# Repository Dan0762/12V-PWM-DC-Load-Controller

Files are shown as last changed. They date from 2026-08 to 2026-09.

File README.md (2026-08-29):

# 12V PWM DC Load Controller

A compact 2-layer PWM controller for 12 V DC loads, designed in Altium Designer.

The project is based on an NE555 timer and an N-channel MOSFET low-side power stage.
It was created as a practical PCB design project focused on schematic design,
component selection, power routing, grounding, DFM and manufacturing output generation.

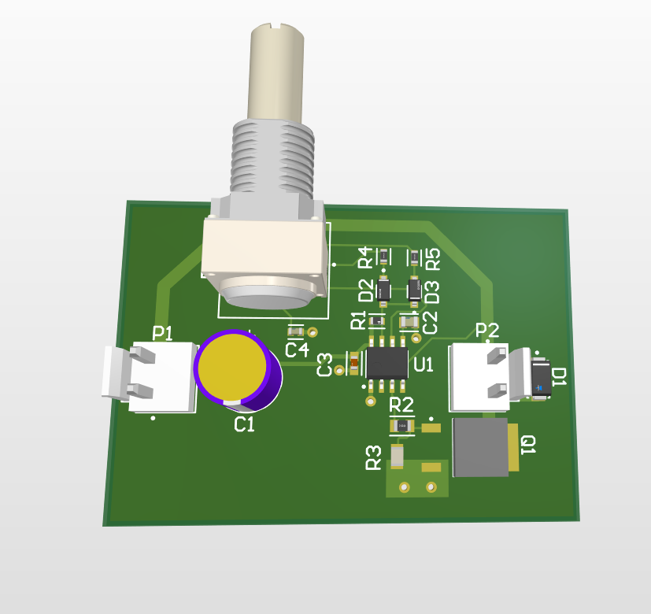
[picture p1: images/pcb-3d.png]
PCB 3D Render


## Overview

The controller generates an adjustable PWM signal at approximately 25 kHz and
switches an external 12 V load using a power MOSFET.

The output can be used with PWM-compatible resistive and inductive loads such as:

- DC motors
- solenoids
- lamps
- resistive heaters
- other 12 V DC loads

A Schottky flyback diode is included for inductive loads.

## Main Features

| Parameter | Value |
|---|---|
| Input voltage | 12 V DC nominal |
| PWM controller | NE555 |
| PWM frequency | ~25 kHz |
| Duty-cycle control | 50 kΩ linear potentiometer |
| Output topology | N-MOSFET low-side switch |
| MOSFET | Infineon IPD053N06N |
| Flyback diode | Vishay SSA34HE3 |
| Target load current | up to ~2 A |
| PCB layers | 2 |
| PCB material | FR-4 |
| PCB thickness | ~1.6 mm |
| Copper thickness | 1 oz |
| PCB software | Altium Designer |

> The ~2 A load capability is a design target. Physical load and thermal
> validation will be performed after PCB assembly.

## Schematic

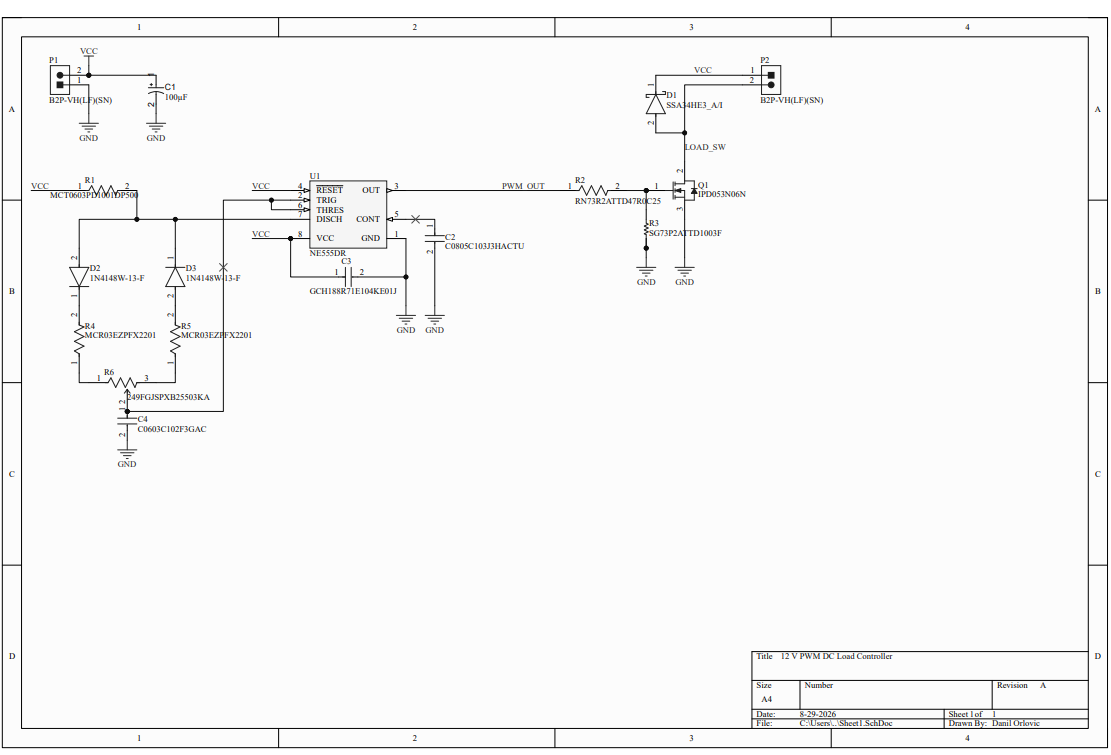
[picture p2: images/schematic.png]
Schematic


The circuit consists of three main functional blocks:

1. 12 V input and local decoupling
2. NE555 adjustable PWM generator
3. N-channel MOSFET power output stage

The NE555 uses separate capacitor charge and discharge paths through two
1N4148W diodes, allowing duty-cycle adjustment with a single potentiometer.

A 1 nF C0G timing capacitor was selected for good frequency stability.

## PCB Design

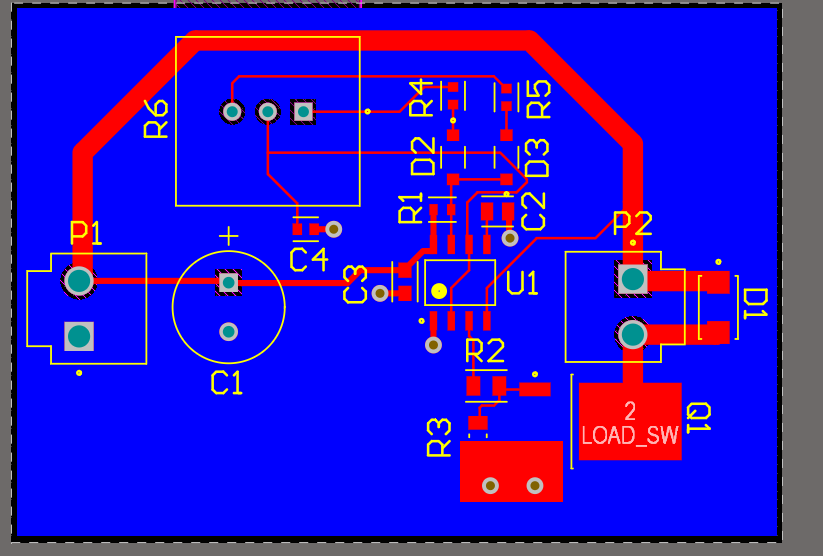
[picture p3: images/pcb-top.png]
PCB Top View


The PCB uses a nearly continuous ground plane on the bottom layer.

The MOSFET source is connected to the ground plane through a wide local copper
area and multiple vias to reduce resistance and inductance in the load-current
return path.

The flyback diode is placed close to the output connector and switching stage
to keep the high-current freewheel loop compact.

## Design Verification

Final Altium PCB Design Rule Check:

- 0 warnings
- 0 rule violations
- 0 unrouted nets

The schematic was also checked using Altium schematic validation/ERC.

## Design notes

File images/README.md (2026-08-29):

# Project Images

Visual documentation for the 12V PWM DC Load Controller.

## 3D PCB Render

3D PCB render

## PCB Top View

PCB top view

## Schematic

Schematic

These images are used in the main project README and documentation.

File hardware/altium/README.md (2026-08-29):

This directory contains the editable Altium Designer source files for the
12V PWM DC Load Controller.

## Files

- `12 V PWM DC Load Controller.PrjPcb` — Altium PCB project
- `Sheet1.SchDoc` — schematic source
- `PCB1.PcbDoc` — PCB layout source

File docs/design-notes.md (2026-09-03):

# Design Notes

## 1. Project Goal

The goal of this project is to design a simple 12 V PWM controller for
DC loads using an NE555 timer and a discrete N-channel MOSFET power stage.

The design is intended as a practical introductory PCB project focused on:

- schematic design
- component selection
- PCB layout
- power routing
- grounding
- design rule verification
- manufacturing output generation

The controller is intended for resistive and inductive 12 V loads such as
small DC motors, solenoids, lamps, and heaters.

## 2. Electrical Architecture

The design consists of three main functional blocks:

1. 12 V input and local decoupling
2. NE555 adjustable PWM generator
3. N-channel MOSFET low-side power switch

The external load is connected between +12 V and the switched LOAD_SW node.

## 3. PWM Generator

The PWM generator is based on the NE555 timer.

Two 1N4148W switching diodes separate the capacitor charge and discharge
paths, allowing the duty cycle to be adjusted using a 50 kOhm linear
potentiometer.

The timing capacitor is:

- 1 nF
- C0G dielectric
- ±1 %

C0G was selected because the timing capacitor directly affects the switching
frequency and benefits from low temperature drift and good capacitance
stability.

The target PWM frequency is approximately 25 kHz.

This places the switching frequency above the normal audible range while
remaining easily achievable with the NE555 and the selected MOSFET.

## 4. Power MOSFET

The output stage uses the Infineon IPD053N06N N-channel MOSFET.

Main parameters:

- VDS: 60 V
- RDS(on): approximately 5.3 mOhm at VGS = 10 V
- DPAK / TO-252 package

The NE555 operates from the 12 V supply, therefore its output provides
sufficient gate voltage for the MOSFET to fully enhance.

A 47 Ohm series gate resistor is used to limit peak gate current and reduce
ringing.

A 100 kOhm gate-to-source resistor ensures that the MOSFET remains off when
the gate is not actively driven.

The gate resistor is placed close to the MOSFET gate.

## 5. Flyback Protection

A Vishay SSA34HE3 Schottky diode is connected across the load output.

The diode provides a freewheel current path when switching inductive loads.

Main parameters:

- 3 A forward current
- 40 V repetitive reverse voltage
- approximately 0.49 V forward voltage
- SMA package

The diode is placed close to the output connector and MOSFET to minimize the
high-current switching loop.

## 6. Decoupling

The design includes:

- 100 uF bulk input capacitor
- 100 nF ceramic decoupling capacitor near the NE555 supply pins
- 10 nF capacitor on the NE555 control-voltage pin

The 100 nF capacitor is placed close to the NE555 and connected to the ground
plane through a short local return path.

## 7. PCB Stackup

The PCB is designed as a standard 2-layer board.

- Material: FR-4
- Board thickness: approximately 1.6 mm
- Copper thickness: 1 oz
- Top layer: components, signals and power routing
- Bottom layer: nearly continuous ground plane

The bottom ground plane is kept as continuous as possible to provide short
return-current paths.

## 8. Grounding Strategy

The design uses a single common ground plane.

Separate analog and power ground planes were not used because the circuit is
simple and does not require split-ground architecture.

Low-current ground connections are routed locally to the bottom ground plane
using vias.

The MOSFET source uses a wide local copper area and multiple vias to connect
to the bottom ground plane and reduce resistance and inductance in the load
current return path.

The MOSFET gate pull-down resistor returns locally to the MOSFET source.

## 9. PCB Design Rules

The PCB uses conservative manufacturing rules.

Main values:

- Minimum track width: 10 mil
- Minimum clearance: 10 mil
- Silk-to-solder-mask clearance: 6 mil
- Standard via: approximately 28 mil / 12 mil drill

These values are intentionally larger than the minimum capabilities of most
modern PCB manufacturers.

## 10. Manufacturing Outputs

The Altium OutJob generates:

- Gerber X2 files
- NC Drill files
- Bill of Materials
- Pick and Place data

Manufacturing files are available in:

[`../manufacturing/`](../manufacturing/)

## 11. Design Verification

Final PCB Design Rule Check:

- 0 warnings
- 0 rule violations
- 0 unrouted nets

The schematic was also checked using Altium schematic validation/ERC.

## 12. Current Status

Rev.A schematic and PCB design are complete.

The PCB has been manufactured, assembled, and electrically tested.

Validation was performed with:
- no load
- resistive load
- inductive load (DC motor)

PWM operation, load behavior, switching waveforms, and component heating were evaluated.

Rev.A is electrically functional and meets the main project goals.

Detailed measurement results and oscilloscope captures are available in
[Validation and Test Results](validation.md).

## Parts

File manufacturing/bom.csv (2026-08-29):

Line # | Name | Description | Designator | Quantity | Manufacturer 1 | Manufacturer Part Number 1 | Manufacturer Lifecycle 1
 | ECA1HM101 | Aluminum Electrolytic Capacitor, 100 uF, +/- 20%, 50 V, -40 to 85 degC, 2-Pin THD, RoHS, Bulk | C1 | 1 | Panasonic | ECA-1HM101 | Volume Production
 | C0805C103J3HACTU | CAP CER 10000PF 25V X8R 0805 | C2 | 1 | Yageo Group | C0805C103J3HACTU | Volume Production
 | GCH188R71E104KE01J | Ceramic Capacitor 100nF ±10% 25V X7R 0603 | C3 | 1 | Deflecto | 73504 | Unknown
 | C0603C102F3GAC | C0603 1,000 pF C0G 30ppm/°C 1.00% 25 V | C4 | 1 | Yageo Group | C0603C102F3GAC | Volume Production
 | SSA34HE3_A/I | DIODE SCHOTTKY 40V 3A DO214AC | D1 | 1 | Vishay | SSA34HE3_A/I | Volume Production
 | 1N4148W-13-F | DIODE GEN PURP 100V 150MA SOD123 | D2, D3 | 2 | Diodes Inc. | 1N4148W-13-F | Volume Production
 | B2P-VH(LF)(SN) | Male Header, Pitch 3.96 mm, 1 x 2 Position, Height 10.9 mm, Tail Length 3.7 mm, -25 to 85 degC, RoHS, Bulk | P1, P2 | 2 | JST | B2P-VH(LF)(SN) | Volume Production
 | IPD053N06N | N-Channel OptiMOS Power-Transistor, 60 V VDS, 45 A ID, -55 to 175 degC, PG-TO252-3-11, Reel, Green | Q1 | 1 | Infineon | IPD053N06NATMA1 | Volume Production
 | MCT0603PD1001DP500 | RES SMD 100 OHM 1% 1/8W 0603 | R1 | 1 | Vishay | MCT0603PD1001DP500 | Volume Production
 | RN73R2ATTD47R0C25 | 47O ±0.25% 0.125W, 1/8W Chip Resistor 0805 (2012 Metric) Moisture Resistant Thin Film | R2 | 1 | KOA Speer | RN73R2ATTD47R0C25 | Volume Production
 | SG73P2ATTD1003F |  | R3 | 1 | KOA Speer | SG73P2ATTD1003F | Volume Production
 | MCR03EZPFX2201 | Thick Film Chip Resistor, 0603, 2.2kO, 1%, 100ppm/°C, 0.1W, 50V | R4, R5 | 2 | ROHM | MCR03EZPFX2201 | Volume Production
 | 249FGJSPXB25503KA | 249FGJSPXB25503KA Res Cermet POT 50K Ohm 20% 1W 1(Elec)/1(Mech)Turn 6.35mm Pin Panel Mount/Through Hole Bulk | R6 | 1 | Vishay | 249FGJSPXB25503KA | Volume Production
 | NE555DR | Precision Timer, 4.5 to 16 V, 0 to 70 degC, 8-Pin SOIC (D), Green (RoHS & no Sb/Br), Tape and Reel | U1 | 1

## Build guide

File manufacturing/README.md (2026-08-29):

# Manufacturing files

`gerbers/` — Gerber X2 fabrication layers
`drill/` — NC Drill files
`BOM.csv` — Bill of Materials
`pick-and-place.csv` — component placement data

Generated from Altium Designer Rev.A sources.

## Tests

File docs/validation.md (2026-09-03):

# Rev.A Validation and Test Results

## 1. Test Setup

Supply voltage: 12 V nominal

Test equipment:
- bench power supply
- digital multimeter
- oscilloscope
- resistive load
- 12 V DC motor

The controller was tested at several duty-cycle settings from the minimum
usable setting up to approximately 95%.

---

## 2. No-Load Test

| Duty setting, % | Vin, V | Iin, mA | PWM frequency, kHz |
|---:|---:|---:|---:|
| 10 | 12.02 | 15 | 24.31 |
| 25 | 12.02 | 13 | 24.00 |
| 50 | 12.02 | 10 | 23.96 |
| 75 | 12.02 | 7 | 23.22 |
| 95 | 12.02 | 3 | 20.33 |

The PWM frequency remained close to 24 kHz through most of the control
range and decreased near the upper end of the adjustment range.

---

## 3. Resistive Load Test

| Duty setting, % | Vin, V | Iin, A | Pin, W | PWM frequency, kHz |
|---:|---:|---:|---:|---:|
| 15 | 11.92 | 0.382 | 4.553 | 24.00 |
| 25 | 11.88 | 0.563 | 6.688 | 24.30 |
| 50 | 11.77 | 0.950 | 11.240 | 24.23 |
| 75 | 11.68 | 1.322 | 15.441 | 23.53 |
| 95 | 11.61 | 1.580 | 18.343 | 20.67 |

---

## 4. Inductive Load Test

A 12 V brushed DC motor was used as the inductive load.

| Duty setting, % | Vin, V | Iin, A | Pin, W | PWM frequency, kHz | Motor behavior |
|---:|---:|---:|---:|---:|---|
| 15 | 12.00 | 0.035 | 0.420 | 24.46 | Did not start |
| 25 | 12.00 | 0.040 | 0.480 | 24.45 | Running |
| 50 | 12.00 | 0.050 | 0.600 | 24.35 | Running |
| 75 | 11.99 | 0.088 | 1.055 | 23.53 | Running |
| 95 | 11.99 | 0.113 | 1.355 | 20.70 | Running |

The motor did not start at the lowest tested duty setting but operated
normally from approximately 25% duty cycle and above.

---

## 5. Oscilloscope Measurements

Oscilloscope measurements were performed under load to verify the MOSFET switching behavior with both resistive and inductive loads.

### 5.1 MOSFET Gate — Resistive Load

Gate waveform measured with a resistive load at approximately 50% duty cycle.

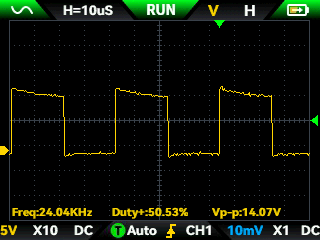
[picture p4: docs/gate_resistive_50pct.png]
MOSFET gate waveform with resistive load at 50% duty


### 5.2 MOSFET Drain — Resistive Load

Drain waveform measured with a resistive load at approximately 50% duty cycle.

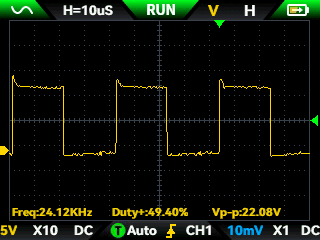
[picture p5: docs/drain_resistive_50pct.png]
MOSFET drain waveform with resistive load at 50% duty


### 5.3 MOSFET Drain — DC Motor Load

Drain waveform measured with a DC motor as the inductive load at approximately 50% duty cycle.

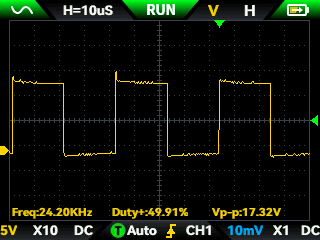
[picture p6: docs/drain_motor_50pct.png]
MOSFET drain waveform with DC motor at 50% duty


## 6. Thermal Observation

During the performed load tests, no significant heating of the MOSFET
or flyback diode was observed.

Because the component temperatures remained low under the tested
conditions, no separate extended thermal test was performed.

---

## 7. Conclusion

Rev.A operated correctly with both resistive and inductive loads.

The PWM controller remained functional across the tested adjustment
range, with the switching frequency remaining near 24 kHz through most
of the range and decreasing near maximum duty.

No abnormal MOSFET or flyback-diode heating was observed during the
performed tests.

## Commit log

2026-08-29 Create gerbers
2026-08-29 Rename Pick Place.csv to pick-and-place.csv
    [pick-and-place.csv]
2026-08-29 Revise README with detailed project information
    Expanded project description and added detailed features, schematic, and PCB design sections.
